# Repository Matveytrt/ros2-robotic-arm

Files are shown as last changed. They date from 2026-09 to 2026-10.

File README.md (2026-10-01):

# ROS2 Robotic Arm

Роборука-манипулятор с 6 степенями свободы из оргстекла. Управление на ROS2 + micro-ROS (ESP32), цифровой двойник, обучение движениям и сортировке кубиков.

Авторы: Разгулов Матвей, Клеукин Вячеслав (Б01-501).

## Структура
| Папка | Что там |
|---|---|
| `roboruka_v1/` | механика: параметрические детали (CadQuery), STEP, DXF для лазера, PDF-чертежи, сборка. Подробности в [roboruka_v1/README.md](roboruka_v1/README.md) |
| `RULES.md` | правила совместной работы: модули, статусы деталей, цикл правки |
| _дальше_ | прошивка micro-ROS, ROS2-пакеты, URDF и цифровой двойник |

## Кинематика v1
J1 основание: NEMA17, прямой привод, упорный подшипник 51106 · J2 плечо: MG996R · J3 локоть: MG996R · J4 наклон кисти: MG90S · J5 вращение клешни: MG90S · J6 захват: MG90S.
Плечо и предплечье по 100 мм. Оргстекло 5 мм на силовые детали, 3 мм на кисть и клешню.

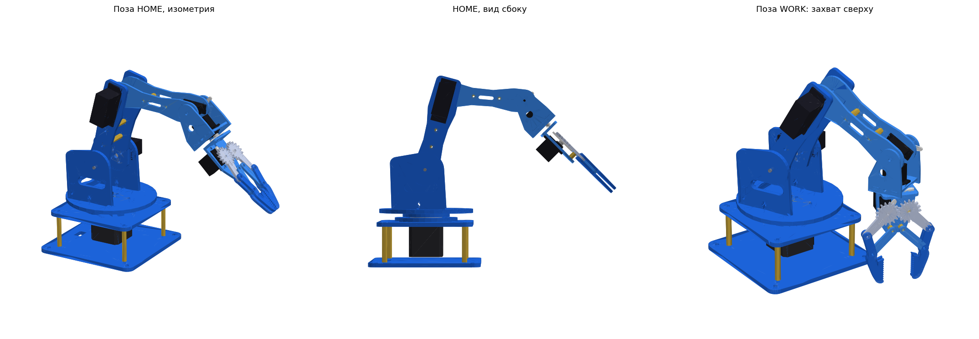
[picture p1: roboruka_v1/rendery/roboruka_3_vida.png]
сборка


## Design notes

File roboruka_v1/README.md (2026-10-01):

# Роборука 6 DOF из оргстекла: заготовки для SolidWorks

## Что внутри
| Папка | Что там |
|---|---|
| `step_detali/` | 21 деталь, каждая в своём STEP. Деталь лежит плоско: контур в плоскости XY, толщина идёт по +Z |
| `sborka/` | сборка в STEP в двух позах: `HOME` и `WORK` (захват сверху). Серво, подшипник, стойки M3 и NEMA17 в ней упрощённые. В сборке «вверх» — это +Y, как принято в SolidWorks |
| `dxf_laser/` | контуры деталей для лазера. `00_list_3mm.dxf` и `00_list_5mm.dxf` — готовые раскладки листов |
| `chertezhi/` | PDF-чертежи: лист 0 — общая схема, дальше по листу на деталь с координатами всех отверстий |
| `rendery/` | картинки сборки и вариантов стиля |
| `scripts/` | исходники. Все размеры лежат в `params.py` |

## Кинематика
- **J1 основание**: NEMA17, прямой привод через фланцевую муфту Ø5, поворот ±180°. Стол лежит на упорном подшипнике 51106, центрируют его кольца 03 и 05.
- **J2 плечо**: MG996R на левой стойке (06), качалка крепится к плечу 09. Правое плечо 10 качается на оси M4 в стойке 07.
- **J3 локоть**: MG996R стоит прямо в локте, на правом плече 10. Его качалка несёт правое предплечье 12, тяги нет.
- **J4 наклон кисти**: MG90S в левом предплечье 11, качалка крепится к кисти 13.
- **J5 вращение клешни**: MG90S на плите 15. Качалка несёт заднюю плиту клешни 16, ось вращения совпадает с осью кисти.
- **J6 захват**: MG90S, пара шестерён m1.5 z16 и два параллелограмма. Пальцы-«клыки» двигаются параллельно, раскрытие 0.6…51 мм.
- Плечо L1 = 100 мм, предплечье L2 = 100 мм, ось плеча на высоте 121 мм от стола.

## Толщины
- 5 мм: 01–10 (основание, стол, кольца, стойки, перемычка, плечи)
- 3 мм: 11–21 (предплечья, кисть, клешня). Палец 21 нужно вырезать 4 шт., поводок 20 — 2 шт.

## Что сверить штангенциркулем (помечено `!!! ПРОВЕРИТЬ` в params.py)
1. **MG996R**: корпус 40.7×19.7, межцентровое ушек 49.5×10, высота от ушка до качалки (`SV_HORN_FACE`), окружность отверстий алюминиевой качалки `HORN_PCD = 18`.
2. **MG90S**: те же размеры, что в клешне v2.
3. **Вылет вала NEMA17** и окружность отверстий фланцевой муфты `CPL_PCD`.

## Крепёж (основной)
- Основание: 4 стойки M3×45 мама-мама, 8 винтов M3×8. NEMA17 крепится 4 винтами M3×10 к плите 02.
- Кольцо 03 крепится к плите 02 винтами M3×12 с гайкой. Кольцо 05 крепится к столу 04 винтами M3×10 в резьбу, нарезанную метчиком.
- Стойки вставляются в стол шипами в пазы и притягиваются Т-соединением (винт M3×12 + гайка в Т-пазу). Так же крепится перемычка 08.
- Плечо: 2 стойки M3×41.5 (или шпилька M3 + трубка), ось M4×50 с нейлоновой гайкой в стойке 07.
- Предплечье: 2 стойки M3×25. Кисть: плита 15 собирается на Т-пазы.
- Клешня: 3 стойки M3×8, шарниры пальцев M3×16 с нейлоновой гайкой.

## Как менять
1. Поменяй число в `scripts/params.py` (например, `L1`, `STYLE`, `FINGER_STYLE`).
2. `pip install cadquery ezdxf shapely matplotlib`
3. `python export.py ../out` пересоберёт STEP, DXF, PDF и сборку. `python check.py` проверит столкновения в 11 позах.

## Импорт в SolidWorks
Открой `.step` через «Файл → Открыть». Деталь придёт телом без дерева. Чтобы получить редактируемый эскиз, открой DXF той же детали: он встанет эскизом на плоскость, дальше «Вытянутая бобышка» на 3 или 5 мм.

## Работа в SolidWorks (папка `solidworks/`)
| Что | Где |
|---|---|
| нативные детали с деревом построения | `solidworks/parts/NN_imya.SLDPRT` |
| общие размеры (T3, T5, D_M3, D_M2, L1, L2…) | `solidworks/params.txt` (детали связаны с ним) |
| описание эскизов для макроса | `solidworks/data/*.txt` (генерирует `scripts/sw_export.py`) |
| макросы | `solidworks/macros/BuildParts.swp`, `ExportAll.swp` (исходники в `.bas`) |

**Дерево каждой детали:**
- `Eskiz_kontur` → `Plastina`: контур, окна, пазы; бобышка на толщину `T3`/`T5`
- `Eskiz_otverstiya` → `Otverstiya`: круглые отверстия с размерами, вырез насквозь. Отверстия M3 привязаны к `D_M3`.

**Как править деталь:**
1. Открой `solidworks/parts/NN_….SLDPRT`.
2. Двойной клик по `Eskiz_otverstiya` или `Eskiz_kontur` → правка → выйти из эскиза → Ctrl+B.
3. Ctrl+S → макрос ExportAll → `python scripts/pipeline.py` → коммит.
4. В `parts.csv` поставь детали статус `manual`, чтобы её больше не перезаписывал генератор.

**Общий размер для всех деталей** (например, зазор под M3): поменяй `"D_M3" = 3.4` в `params.txt` → открой деталь → Ctrl+Q.

**Макросы:** Инструменты → Макрос → Выполнить → `solidworks/macros/…swp`.
- `BuildParts`: спросит номера деталей (`09,20`), пусто = все `gen`.
- `ExportAll`: STEP открытой детали или всех деталей в `step_detali/`.

## Модули (подсборки)
- Таблица интерфейсов `PORTS` в `scripts/moduli.py`: модуль → родитель, шарнир, точка порта и ось. По ней же потом соберём URDF для ROS2.
- `python scripts/moduli.py ..` раскладывает компоненты по модулям в их собственных СК и проверяет, что модули, собранные по портам в другой позе, совпадают с исходной сборкой (сейчас расхождение 1e-12 мм). Результат: `sborka/moduli/M*.step` и данные для SolidWorks в `solidworks/moduli/*.txt`.
- Макрос **BuildAssembly** (`solidworks/macros/BuildAssembly.swp`):
  - покупные изделия `solidworks/pokupnye/*.step` переводит в SLDPRT;
  - собирает `solidworks/moduli/M1…M6.SLDASM` (детали внутри модуля зафиксированы);
  - собирает `solidworks/roboruka_HOME.SLDASM` из шести модулей в позе HOME.
- Пока модули в общей сборке тоже зафиксированы. Подвижные сопряжения по портам (крутить руку мышкой) — следующий шаг.

Правила совместной работы — в [`../RULES.md`](../RULES.md).

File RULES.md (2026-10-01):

# Правила работы над роборукой (Матвей + Claude)

## 1. Модули и интерфейсы
Рука собирается из шести модулей, как из лего. У каждого модуля своя система координат: **начало на входном шарнире**.

| Модуль | Детали | Вход (шарнир, ось в СК родителя) |
|---|---|---|
| M1_osnovanie | 01–03, NEMA17, подшипник 51106 | — (стоит на столе) |
| M2_platforma | 04–08, MG996R плеча, ось M4 | J1: (0, 0, 66), ось Z |
| M3_plecho | 09, 10, MG996R локтя, качалка плеча | J2: (0, 0, 55), ось −Y |
| M4_predplechye | 11, 12, MG90S наклона, качалка локтя | J3: (L1, 0, 0), ось −Y |
| M5_kist | 13–15, MG90S вращения, качалка наклона | J4: (L2, 0, 0), ось −Y |
| M6_kleshnya | 16–21, MG90S захвата, качалка вращения | J5: (46, 0, 0), ось X |

**Интерфейс — это ровно одна строка таблицы `PORTS` в `roboruka_v1/scripts/moduli.py`**, то есть точка и ось шарнира в СК родителя. Больше нигде порты не записаны.
- Внутри модуля меняй что угодно, пока деталь не лезет на место порта.
- Качалка серво относится к модулю, который она двигает (модулю-ребёнку), а корпус серво — к модулю-родителю.
- Меняешь порт — это изменение двух модулей сразу. Пиши в коммите `M3↔M4: …`; `moduli.py` проверит, что модули по-прежнему стыкуются.
- Где лежат модули: в STEP — `sborka/moduli/M*.step`, в SolidWorks — `solidworks/moduli/M*.SLDASM`. Общая сборка из модулей: `solidworks/roboruka_HOME.SLDASM`.

## 2. У каждой детали один хозяин
Колонка `status` в `roboruka_v1/parts.csv`:
- `gen` — геометрию строит Python, а SLDPRT собирает макрос BuildParts. Деталь правим через `params.py` / `params.txt`.
- `manual` — деталь правишь ты в SolidWorks. Python её **никогда** не перегенерирует, а берёт её STEP, который сохранил SolidWorks.

Чтобы забрать деталь себе: поставь в `parts.csv` статус `manual` и закоммить. Обратно `gen` — только по договорённости, иначе потеряются ручные правки.

## 3. Геометрия детали
- **Начало координат детали = ось её главного шарнира. Не двигать.** По этой точке деталь ставится в сборку.
- Деталь лежит в плоскости «Спереди» (XY), толщина идёт в +Z.
- Толщина детали задаётся только через глобальные переменные `T3` / `T5`, отверстия M3 — через `D_M3`.
- Единицы: мм. Зазоры: M3 → 3.3 мм, паз-шип 0.2 мм.

## 4. Файлы и имена
- `NN_imya.SLDPRT` и `NN_imya.step` с одинаковым именем. Номер детали не меняется никогда.
- Никаких `_v2`, `_final`, `_new`: версии хранит git.
- Все SLDPRT/SLDASM лежат внутри `Fabrica`, иначе сломаются ссылки сборок.

## 5. Цикл после правки
1. Поправил деталь в SolidWorks → сохранил (Ctrl+S).
2. Макрос **ExportAll** → STEP в `step_detali/`.
3. `python scripts/pipeline.py` → DXF, листы на резку, чертежи, модули, проверка портов и столкновений. Можно попросить Claude.
4. Если менялся состав или положение деталей в модуле → макрос **BuildAssembly** (пересоберёт `M*.SLDASM` и `roboruka_HOME.SLDASM`).
5. `git add -A && git commit -m "M6: палец длиннее на 5 мм"` → `git push`.
- Один коммит = одна осмысленная правка.
- Эксперименты делаем в ветке: `git switch -c opyt-palec`.

## 6. Замеры
Всё, что измерено штангенциркулем, вносим в `params.py` с пометкой `# измерено ДД.ММ`. Пока стоит `!!! ПРОВЕРИТЬ`, размер считается предварительным.

## 7. Claude обещает
- Сначала задаёт вопросы, потом проектирует. Никакой отсебятины.
- Не трогает детали `manual` и не меняет интерфейсы молча.
- Не пушит без Матвея. Сам коммитит только то, что сделал, с понятным сообщением.
- После каждой правки объясняет, что поменял и почему.

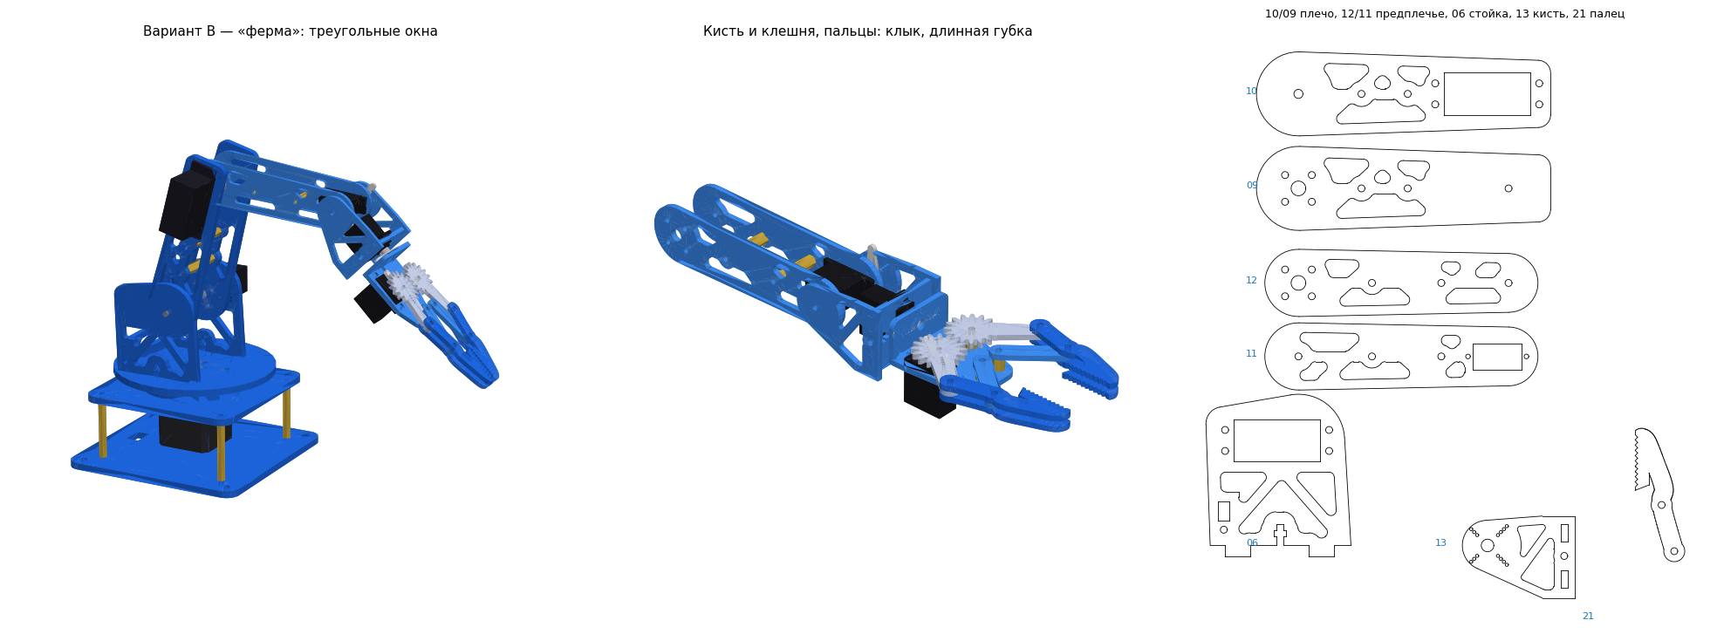
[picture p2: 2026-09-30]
roboruka_v1/rendery/variant_B.png

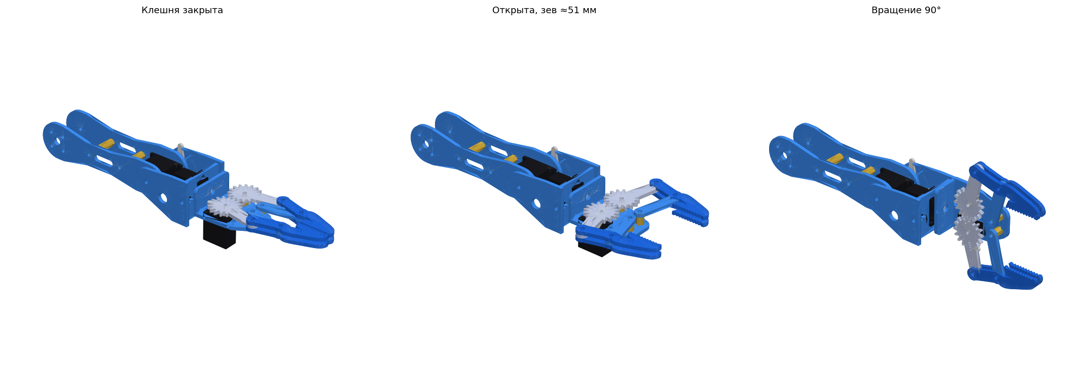
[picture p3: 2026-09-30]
roboruka_v1/rendery/kist_i_kleshnya.png

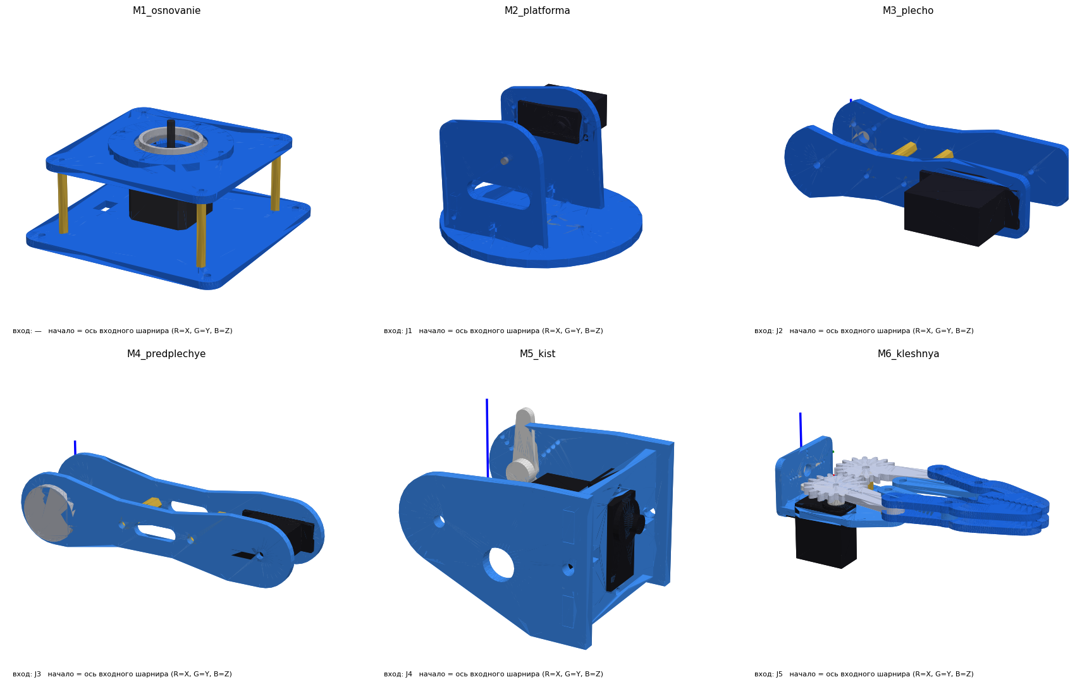
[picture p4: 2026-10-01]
roboruka_v1/rendery/moduli.png

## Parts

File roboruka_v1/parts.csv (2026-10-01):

pid | name | module | status | thickness | qty | note
01 | 01_osnovanie_niz | M1_osnovanie | gen | 5 | 1 | Основание нижнее
02 | 02_plita_dvigatelya | M1_osnovanie | gen | 5 | 1 | Плита двигателя (верх основания)
03 | 03_kolco_nizhnee | M1_osnovanie | gen | 5 | 1 | Кольцо-центратор нижнее (51106)
04 | 04_povorotny_stol | M2_platforma | gen | 5 | 1 | Поворотный стол
05 | 05_kolco_verhnee | M2_platforma | gen | 5 | 1 | Кольцо-центратор верхнее (резьба M3 метчиком)
06 | 06_stoyka_levaya | M2_platforma | gen | 5 | 1 | Стойка левая (MG996R плеча)
07 | 07_stoyka_pravaya | M2_platforma | gen | 5 | 1 | Стойка правая (ось M4)
08 | 08_peremychka | M2_platforma | gen | 5 | 1 | Задняя перемычка стоек
09 | 09_plecho_levoe | M3_plecho | gen | 5 | 1 | Плечо левое (на качалке MG996R плеча)
10 | 10_plecho_pravoe | M3_plecho | gen | 5 | 1 | Плечо правое (MG996R локтя)
11 | 11_predplechye_levoe | M4_predplechye | gen | 3 | 1 | Предплечье левое (MG90S наклона)
12 | 12_predplechye_pravoe | M4_predplechye | gen | 3 | 1 | Предплечье правое (на качалке локтя)
13 | 13_kist_A | M5_kist | gen | 3 | 1 | Кисть A (на качалке наклона)
14 | 14_kist_B | M5_kist | gen | 3 | 1 | Кисть B (на оси)
15 | 15_kist_plita | M5_kist | gen | 3 | 1 | Плита сервы вращения
16 | 16_kleshnya_zad | M6_kleshnya | gen | 3 | 1 | Задняя плита клешни (на качалке вращения)
17 | 17_ladon | M6_kleshnya | gen | 3 | 1 | Ладонь клешни
18 | 18_shesternya_R | M6_kleshnya | gen | 3 | 1 | Шестерня-рычаг R ведущая (на качалке)
19 | 19_shesternya_L | M6_kleshnya | gen | 3 | 1 | Шестерня-рычаг L ведомая
20 | 20_povodok | M6_kleshnya | gen | 3 | 2 | Поводок (левый = правый)
21 | 21_palec | M6_kleshnya | gen | 3 | 4 | Палец (4 одинаковых, левые перевёрнуты)

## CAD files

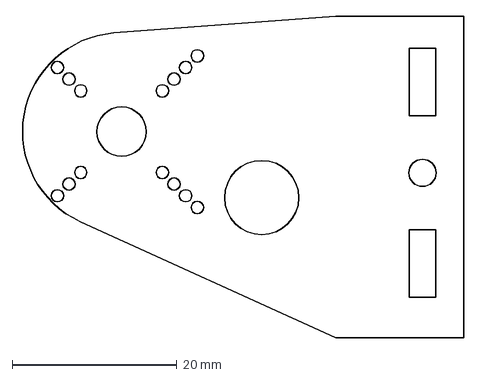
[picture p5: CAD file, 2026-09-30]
roboruka_v1/dxf_laser/13_kist_A.dxf
54.3 x 39.0 mm

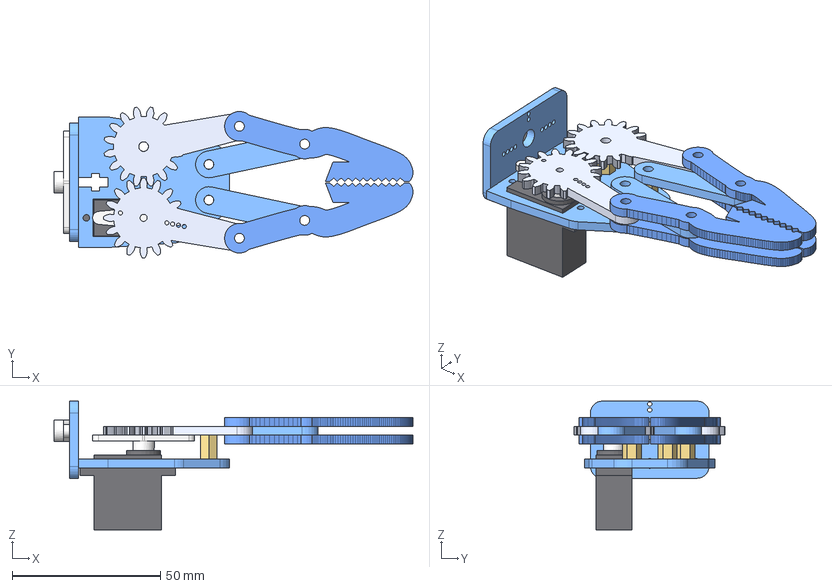
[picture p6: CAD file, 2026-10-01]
roboruka_v1/sborka/moduli/M6_kleshnya.step
121.0 x 50.8 x 43.4 mm
16_kleshnya_zad
17_ladon
18_shesternya_R
19_shesternya_L
20_povodok_R
20_povodok_L
21_palec_R_verh
21_palec_R_niz
21_palec_L_verh
21_palec_L_niz
MG90S_zahvat
kachalka_zahvat
stoyka_M3x8_kleshnya_0
stoyka_M3x8_kleshnya_1
stoyka_M3x8_kleshnya_2
kachalka_vrashenie

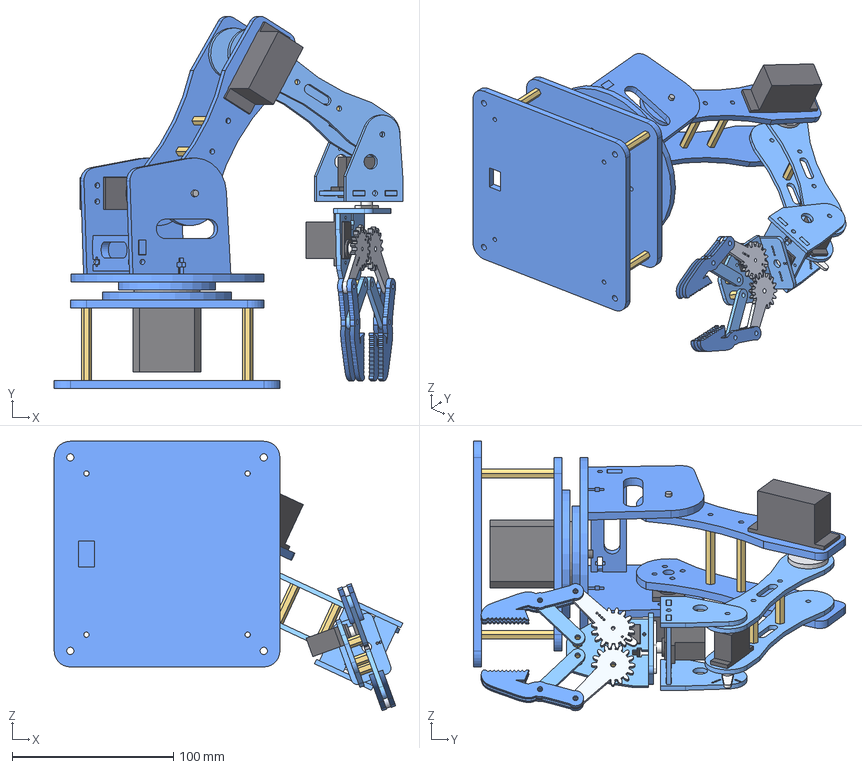
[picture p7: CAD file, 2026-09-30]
roboruka_v1/sborka/roboruka_sborka_WORK.step
216.2 x 230.7 x 167.2 mm
01_osnovanie_niz
02_plita_dvigatelya
03_kolco_nizhnee
stoyka_M3x45
stoyka_M3x45_2
stoyka_M3x45_3
stoyka_M3x45_4
NEMA17
51106_nizhnyaya_shayba
51106_separator
51106_verhnyaya_shayba
05_kolco_verhnee
04_povorotny_stol
mufta_flanc_5mm
06_stoyka_levaya
07_stoyka_pravaya
08_peremychka
MG996R_plecho
kachalka_plecho
MG996R_lokot
kachalka_lokot
os_M4_plecho
09_plecho_levoe
10_plecho_pravoe
11_predplechye_levoe
12_predplechye_pravoe
stoyka_M3x41.5_plecho_0
stoyka_M3x41.5_plecho_1
stoyka_M3x25_predpl_0
stoyka_M3x25_predpl_1
MG90S_naklon
13_kist_A
14_kist_B
15_kist_plita
kachalka_naklon
MG90S_vrashenie
16_kleshnya_zad
17_ladon
18_shesternya_R
19_shesternya_L
20_povodok_R
20_povodok_L
21_palec_R_verh
21_palec_R_niz
21_palec_L_verh
21_palec_L_niz
MG90S_zahvat
kachalka_zahvat
stoyka_M3x8_kleshnya_0
stoyka_M3x8_kleshnya_1
stoyka_M3x8_kleshnya_2
kachalka_vrashenie

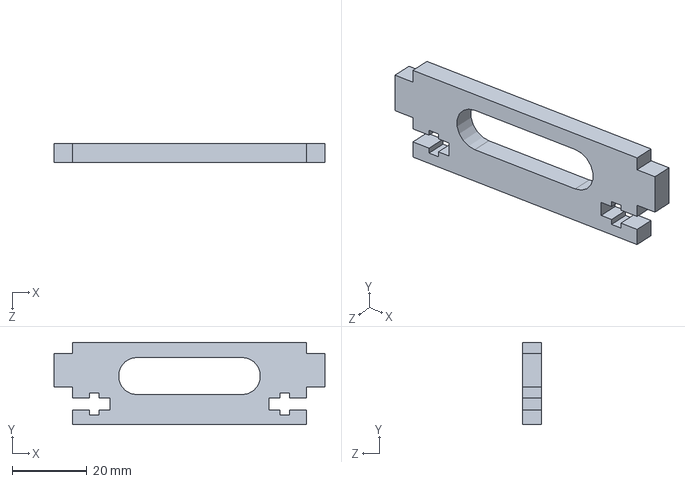
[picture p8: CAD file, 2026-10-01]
roboruka_v1/solidworks/parts/08_peremychka.SLDPRT
72.5 x 22.0 x 5.00 mm

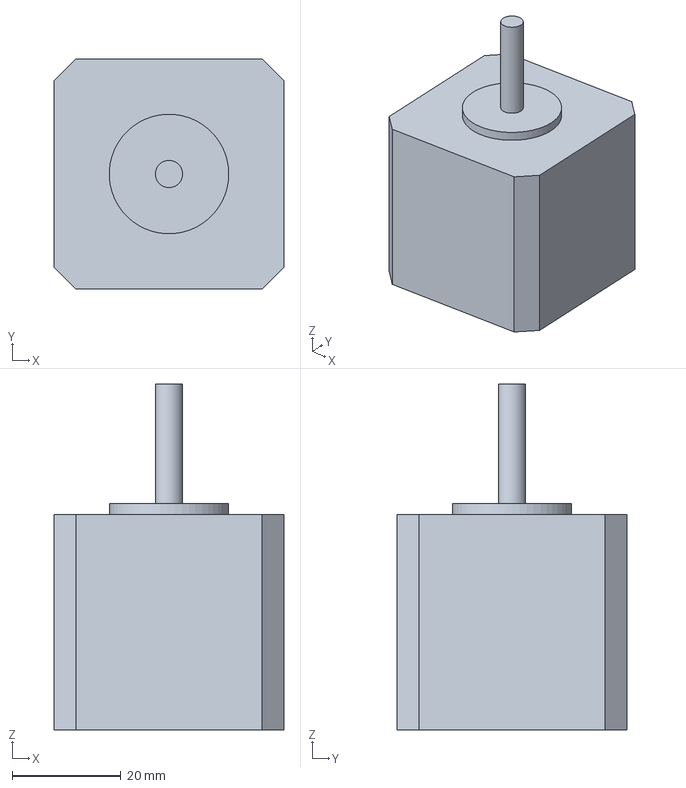
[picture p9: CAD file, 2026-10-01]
roboruka_v1/solidworks/pokupnye/NEMA17.step
42.3 x 42.3 x 63.7 mm

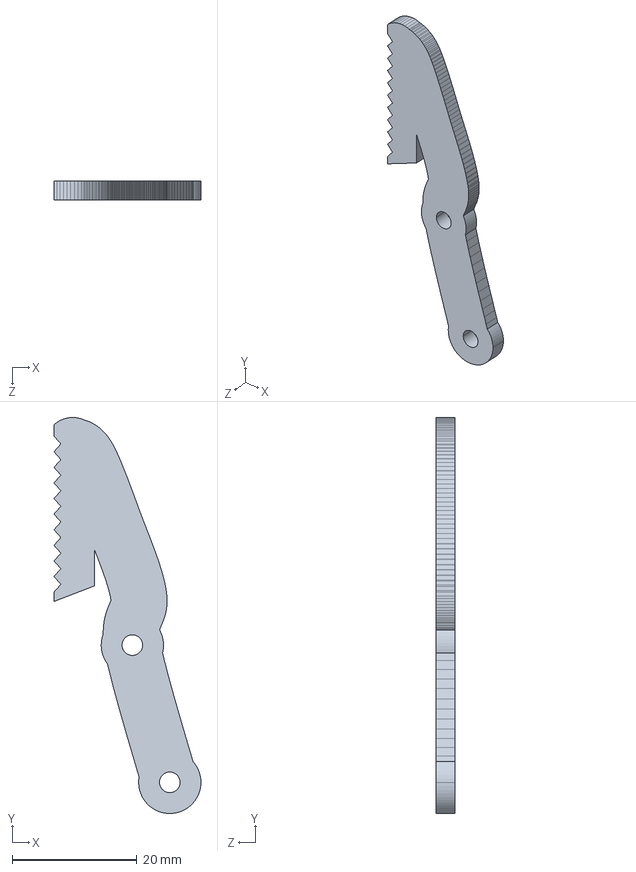
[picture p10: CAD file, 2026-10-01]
roboruka_v1/step_detali/21_palec.step
23.6 x 63.5 x 3.00 mm

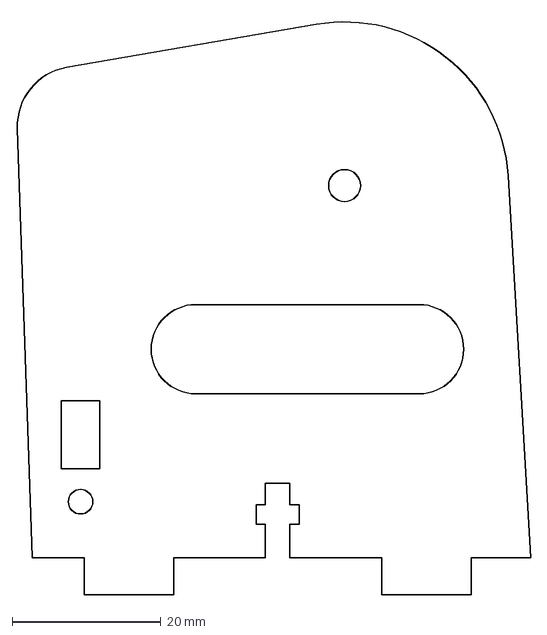
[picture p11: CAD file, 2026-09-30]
roboruka_v1/dxf_laser/07_stoyka_pravaya.dxf
69.1 x 77.8 mm

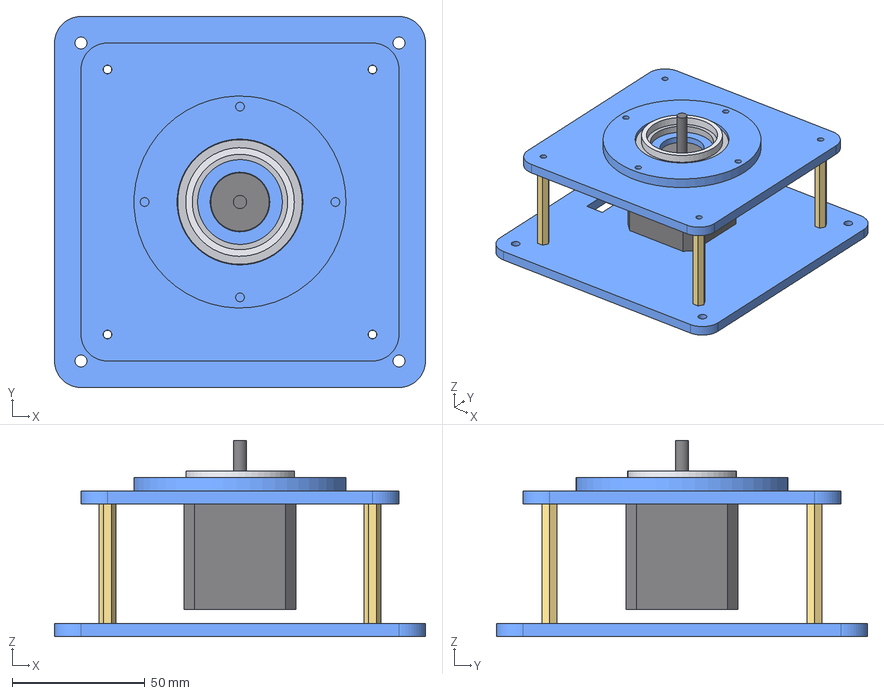
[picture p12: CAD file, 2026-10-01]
roboruka_v1/sborka/moduli/M1_osnovanie.step
140.0 x 140.0 x 74.0 mm
01_osnovanie_niz
02_plita_dvigatelya
03_kolco_nizhnee
stoyka_M3x45
stoyka_M3x45_2
stoyka_M3x45_3
stoyka_M3x45_4
NEMA17
51106_nizhnyaya_shayba
51106_separator

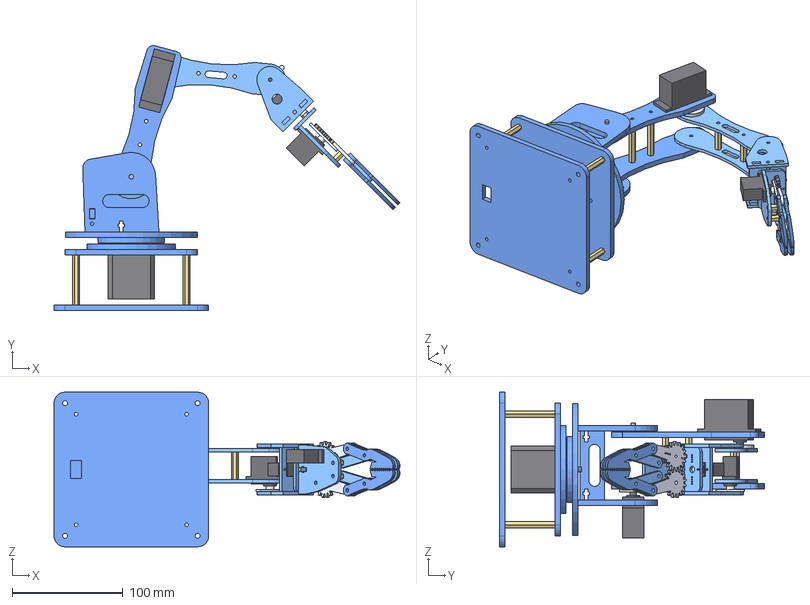
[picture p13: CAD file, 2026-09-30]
roboruka_v1/sborka/roboruka_sborka_HOME.step
313.1 x 239.7 x 140.0 mm
01_osnovanie_niz
02_plita_dvigatelya
03_kolco_nizhnee
stoyka_M3x45
stoyka_M3x45_2
stoyka_M3x45_3
stoyka_M3x45_4
NEMA17
51106_nizhnyaya_shayba
51106_separator
51106_verhnyaya_shayba
05_kolco_verhnee
04_povorotny_stol
mufta_flanc_5mm
06_stoyka_levaya
07_stoyka_pravaya
08_peremychka
MG996R_plecho
kachalka_plecho
MG996R_lokot
kachalka_lokot
os_M4_plecho
09_plecho_levoe
10_plecho_pravoe
11_predplechye_levoe
12_predplechye_pravoe
stoyka_M3x41.5_plecho_0
stoyka_M3x41.5_plecho_1
stoyka_M3x25_predpl_0
stoyka_M3x25_predpl_1
MG90S_naklon
13_kist_A
14_kist_B
15_kist_plita
kachalka_naklon
MG90S_vrashenie
16_kleshnya_zad
17_ladon
18_shesternya_R
19_shesternya_L
20_povodok_R
20_povodok_L
21_palec_R_verh
21_palec_R_niz
21_palec_L_verh
21_palec_L_niz
MG90S_zahvat
kachalka_zahvat
stoyka_M3x8_kleshnya_0
stoyka_M3x8_kleshnya_1
stoyka_M3x8_kleshnya_2
kachalka_vrashenie

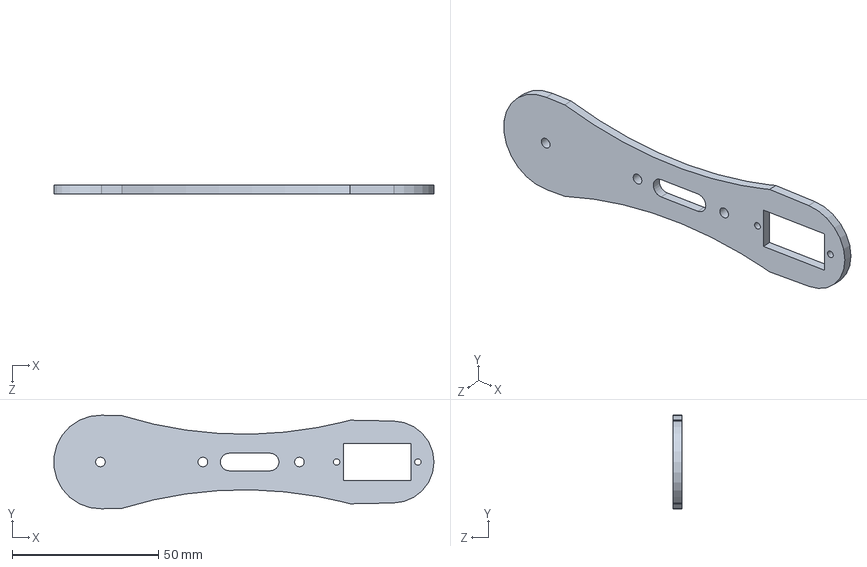
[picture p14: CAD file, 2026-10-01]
roboruka_v1/solidworks/parts/11_predplechye_levoe.SLDPRT
129.9 x 32.0 x 3.00 mm

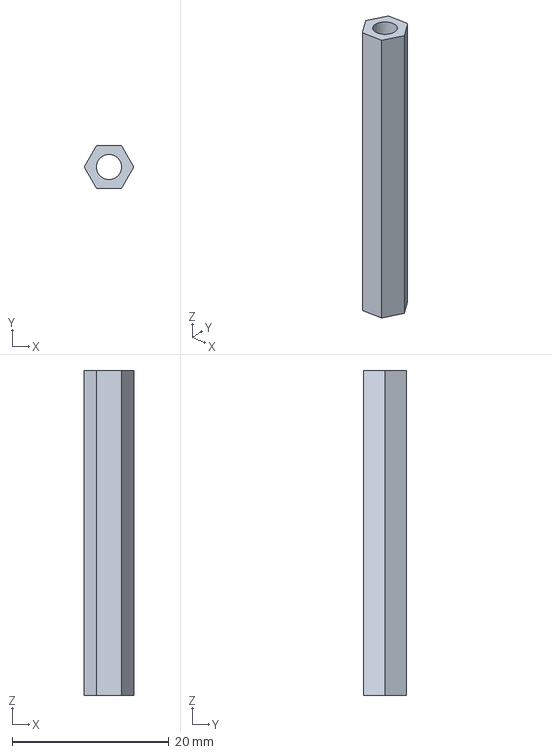
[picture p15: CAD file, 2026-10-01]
roboruka_v1/solidworks/pokupnye/stoyka_M3x41_5.step
6.35 x 5.50 x 41.5 mm

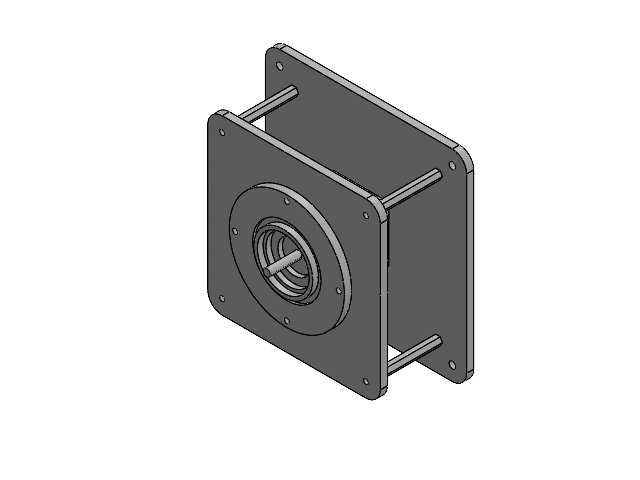
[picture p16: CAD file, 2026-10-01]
roboruka_v1/solidworks/moduli/M1_osnovanie.SLDASM
01_osnovanie_niz
02_plita_dvigatelya
03_kolco_nizhnee
stoyka_M3x45 x 4
NEMA17
51106_shayba_niz
51106_separator

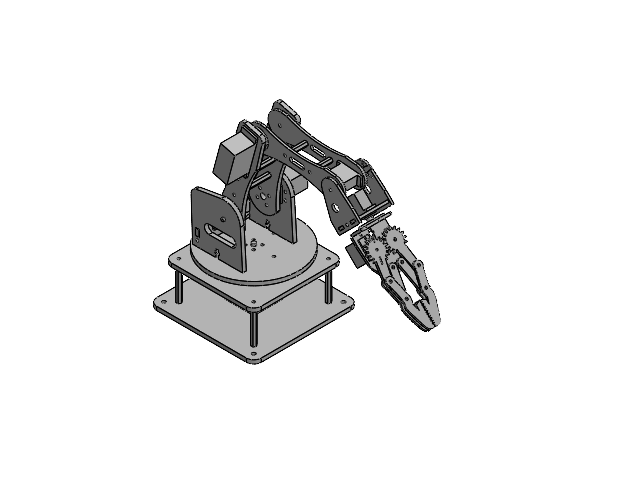
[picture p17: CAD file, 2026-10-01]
roboruka_v1/solidworks/roboruka_HOME.SLDASM
01_osnovanie_niz
02_plita_dvigatelya
03_kolco_nizhnee
stoyka_M3x45 x 4
NEMA17
51106_shayba_niz
51106_separator
51106_shayba_verh
05_kolco_verhnee
04_povorotny_stol
mufta_flanc_5mm
06_stoyka_levaya
07_stoyka_pravaya
08_peremychka
MG996R x 2
os_M4
kachalka_MG996R x 2
09_plecho_levoe
10_plecho_pravoe
stoyka_M3x41_5 x 2
11_predplechye_levoe
12_predplechye_pravoe
stoyka_M3x25 x 2
MG90S x 3
13_kist_A
14_kist_B
15_kist_plita
kachalka_MG90S x 3
16_kleshnya_zad
17_ladon
18_shesternya_R
19_shesternya_L
20_povodok x 2
21_palec x 4
stoyka_M3x8 x 3

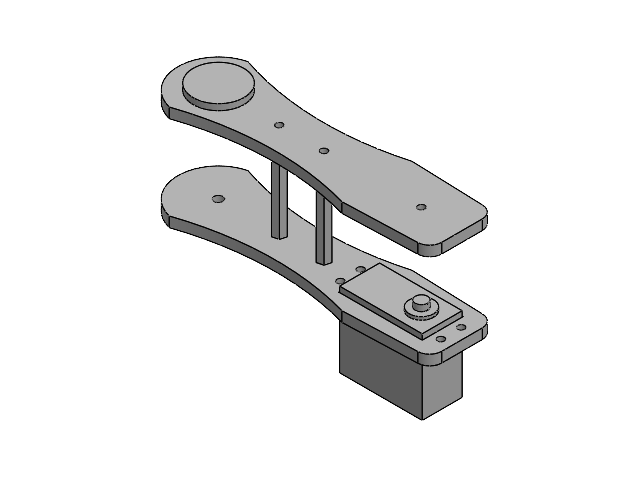
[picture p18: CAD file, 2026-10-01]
roboruka_v1/solidworks/moduli/M3_plecho.SLDASM
kachalka_MG996R
MG996R
09_plecho_levoe
10_plecho_pravoe
stoyka_M3x41_5 x 2

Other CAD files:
roboruka_v1/solidworks/moduli/M2_platforma.SLDASM
roboruka_v1/solidworks/moduli/M6_kleshnya.SLDASM
roboruka_v1/solidworks/moduli/M4_predplechye.SLDASM
roboruka_v1/solidworks/moduli/M5_kist.SLDASM
roboruka_v1/dxf_laser/00_list_3mm.dxf
roboruka_v1/dxf_laser/00_list_5mm.dxf
roboruka_v1/dxf_laser/01_osnovanie_niz.dxf
roboruka_v1/dxf_laser/02_plita_dvigatelya.dxf
roboruka_v1/dxf_laser/03_kolco_nizhnee.dxf
roboruka_v1/dxf_laser/04_povorotny_stol.dxf
roboruka_v1/dxf_laser/05_kolco_verhnee.dxf
roboruka_v1/dxf_laser/06_stoyka_levaya.dxf
roboruka_v1/dxf_laser/08_peremychka.dxf
roboruka_v1/dxf_laser/09_plecho_levoe.dxf
roboruka_v1/dxf_laser/10_plecho_pravoe.dxf
roboruka_v1/dxf_laser/11_predplechye_levoe.dxf
roboruka_v1/dxf_laser/12_predplechye_pravoe.dxf
roboruka_v1/dxf_laser/14_kist_B.dxf
roboruka_v1/dxf_laser/15_kist_plita.dxf
roboruka_v1/dxf_laser/16_kleshnya_zad.dxf
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

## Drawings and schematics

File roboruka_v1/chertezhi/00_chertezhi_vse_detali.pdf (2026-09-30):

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

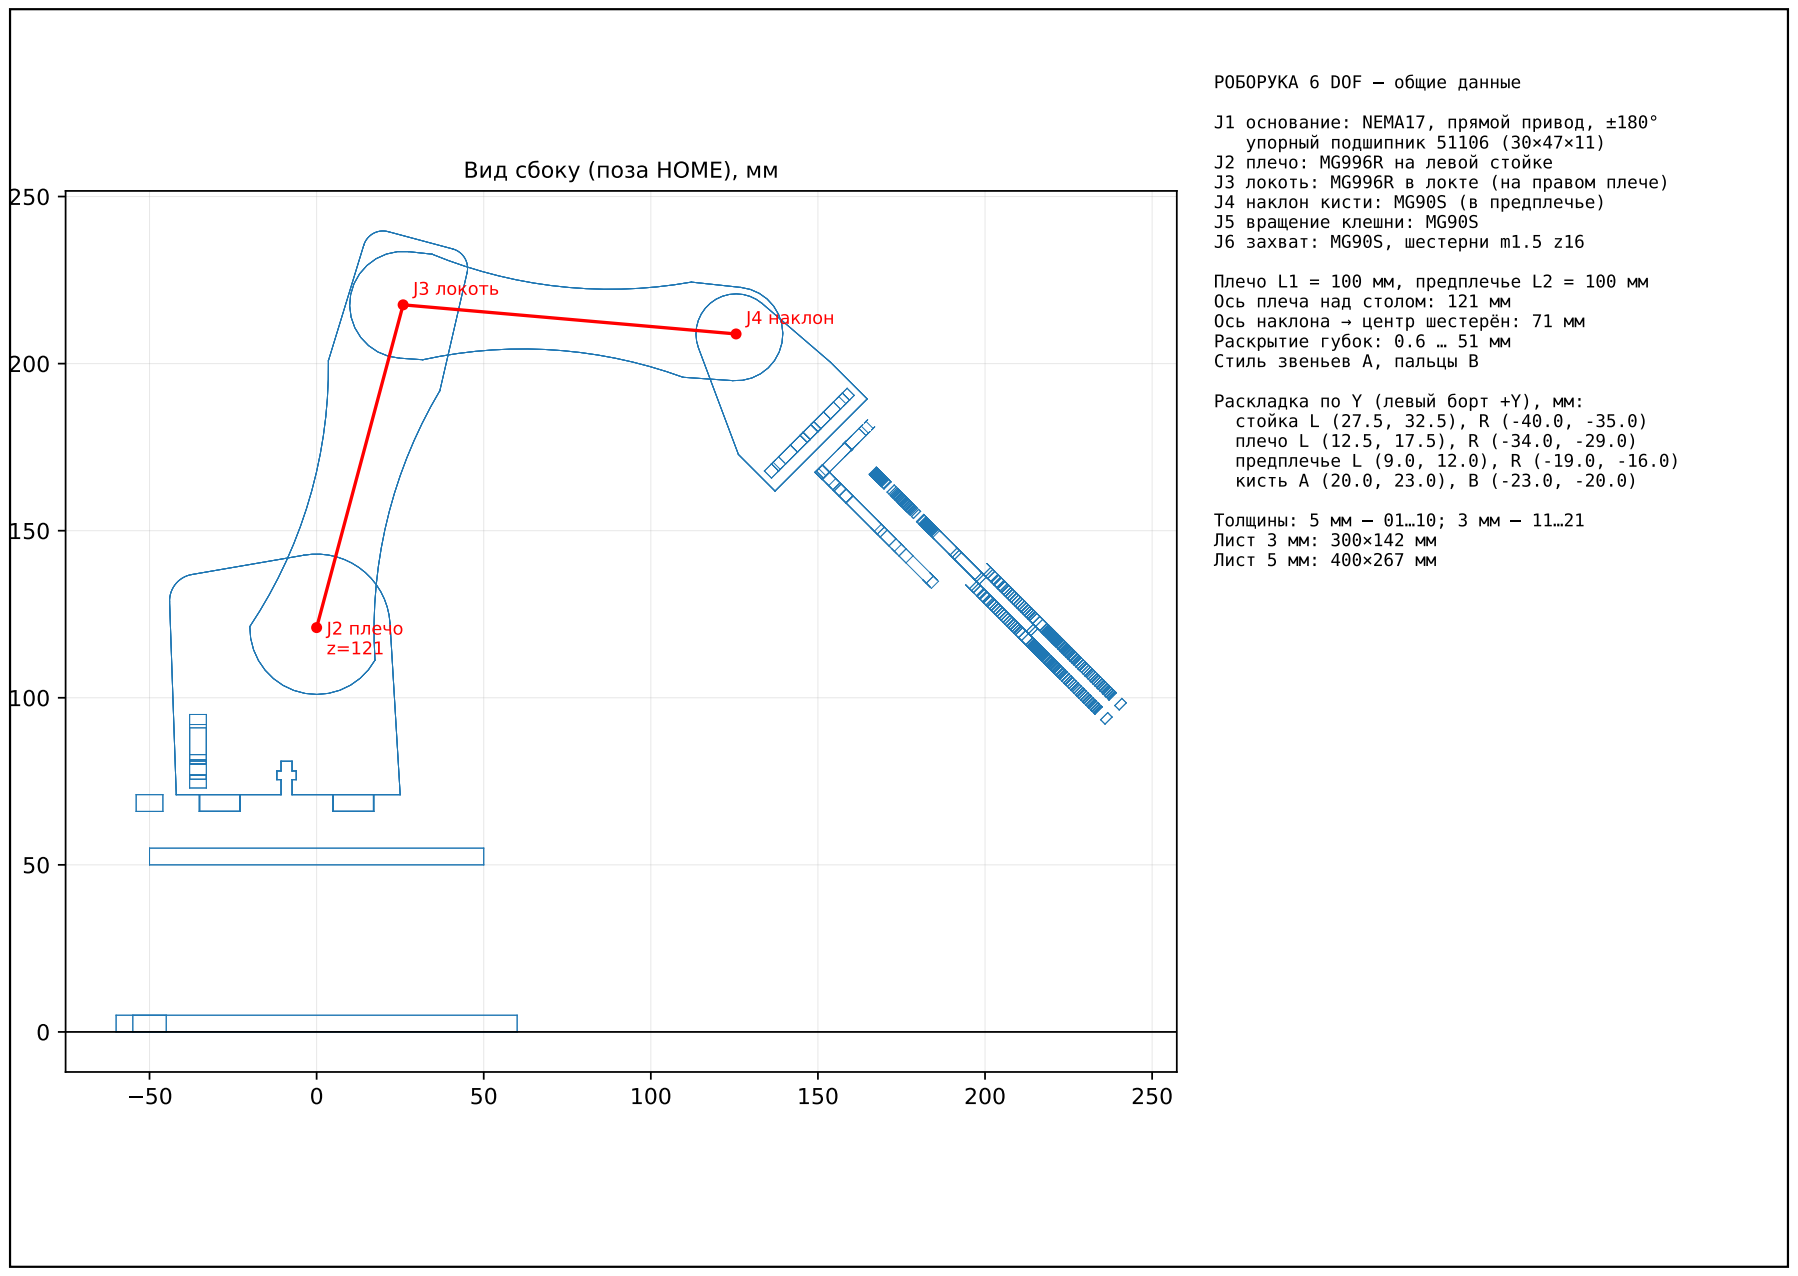
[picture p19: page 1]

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

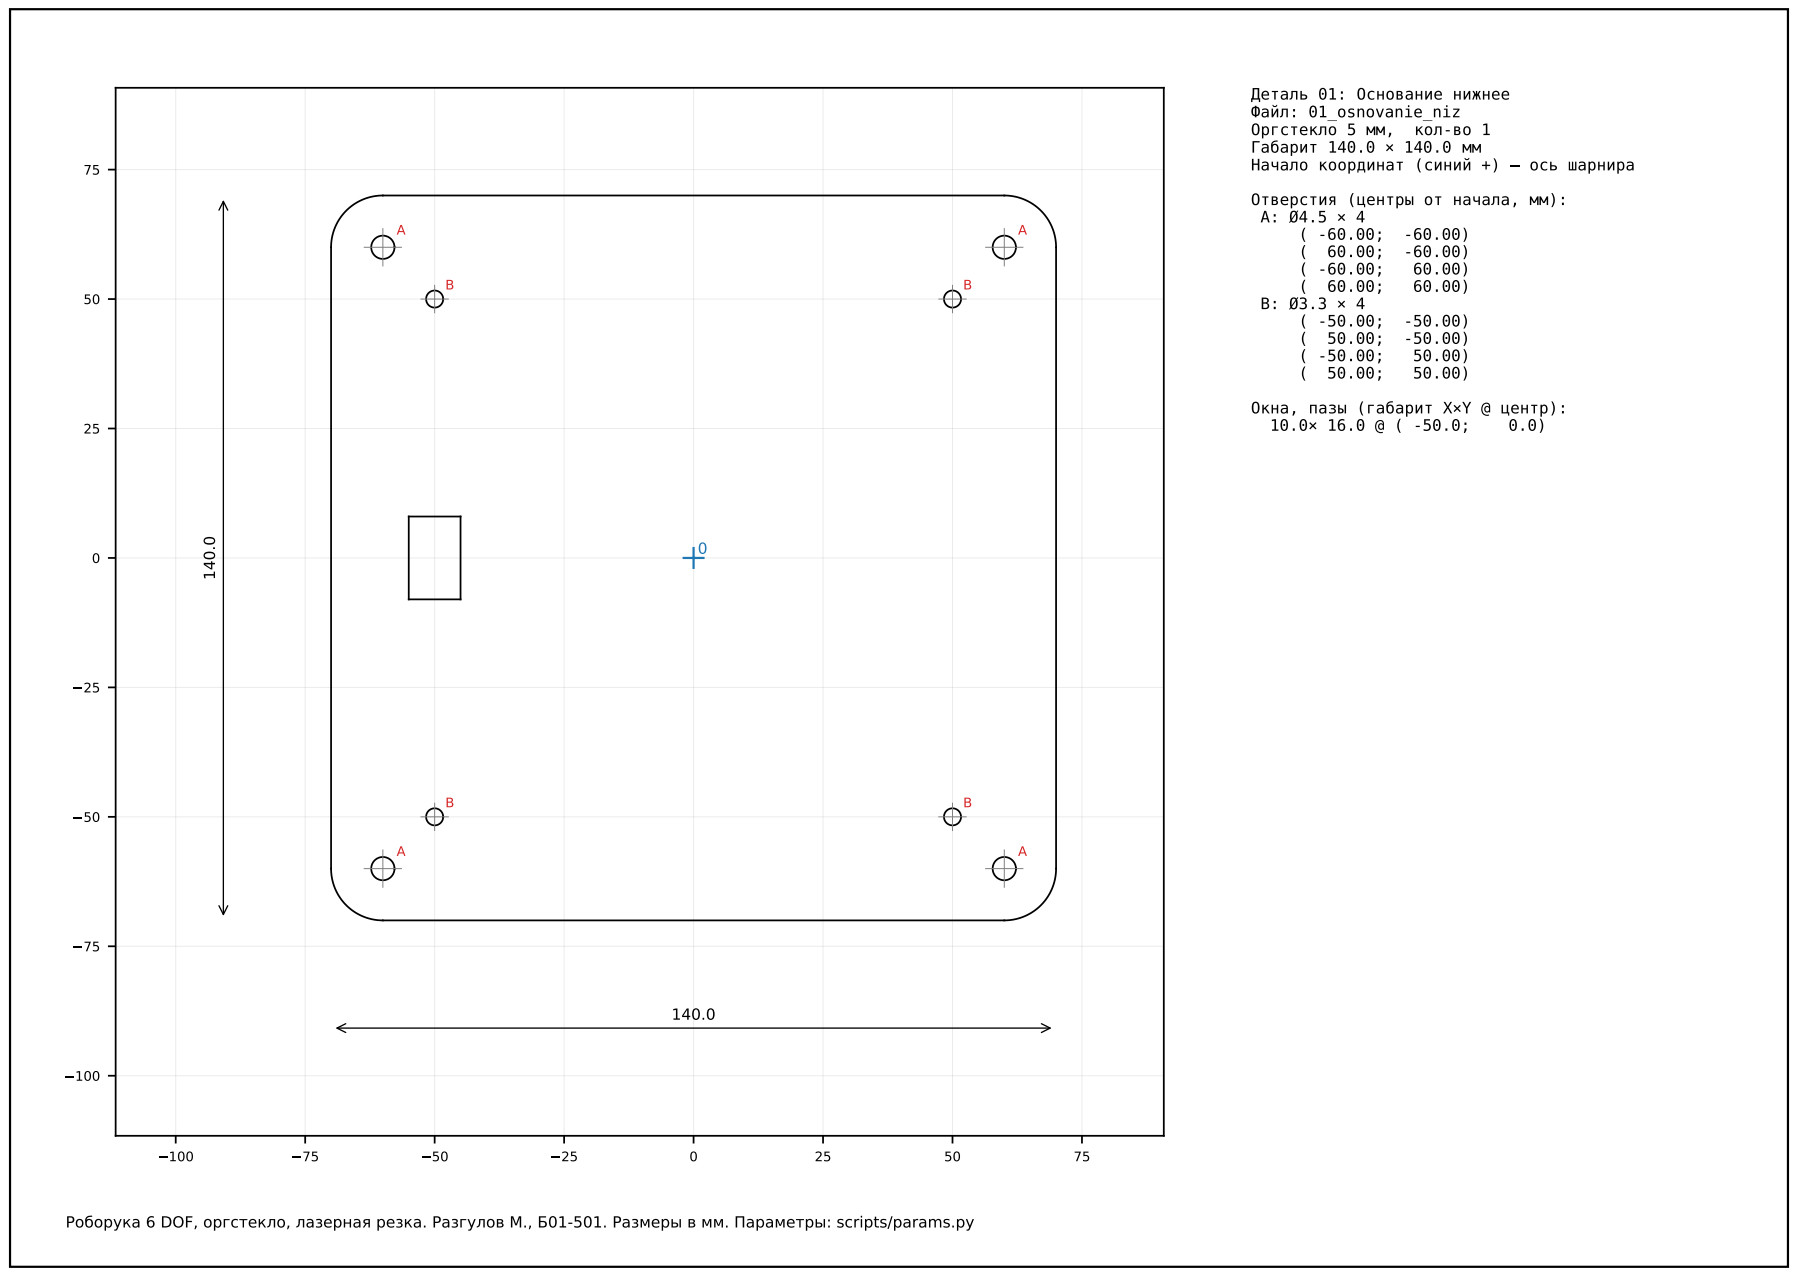
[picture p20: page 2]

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

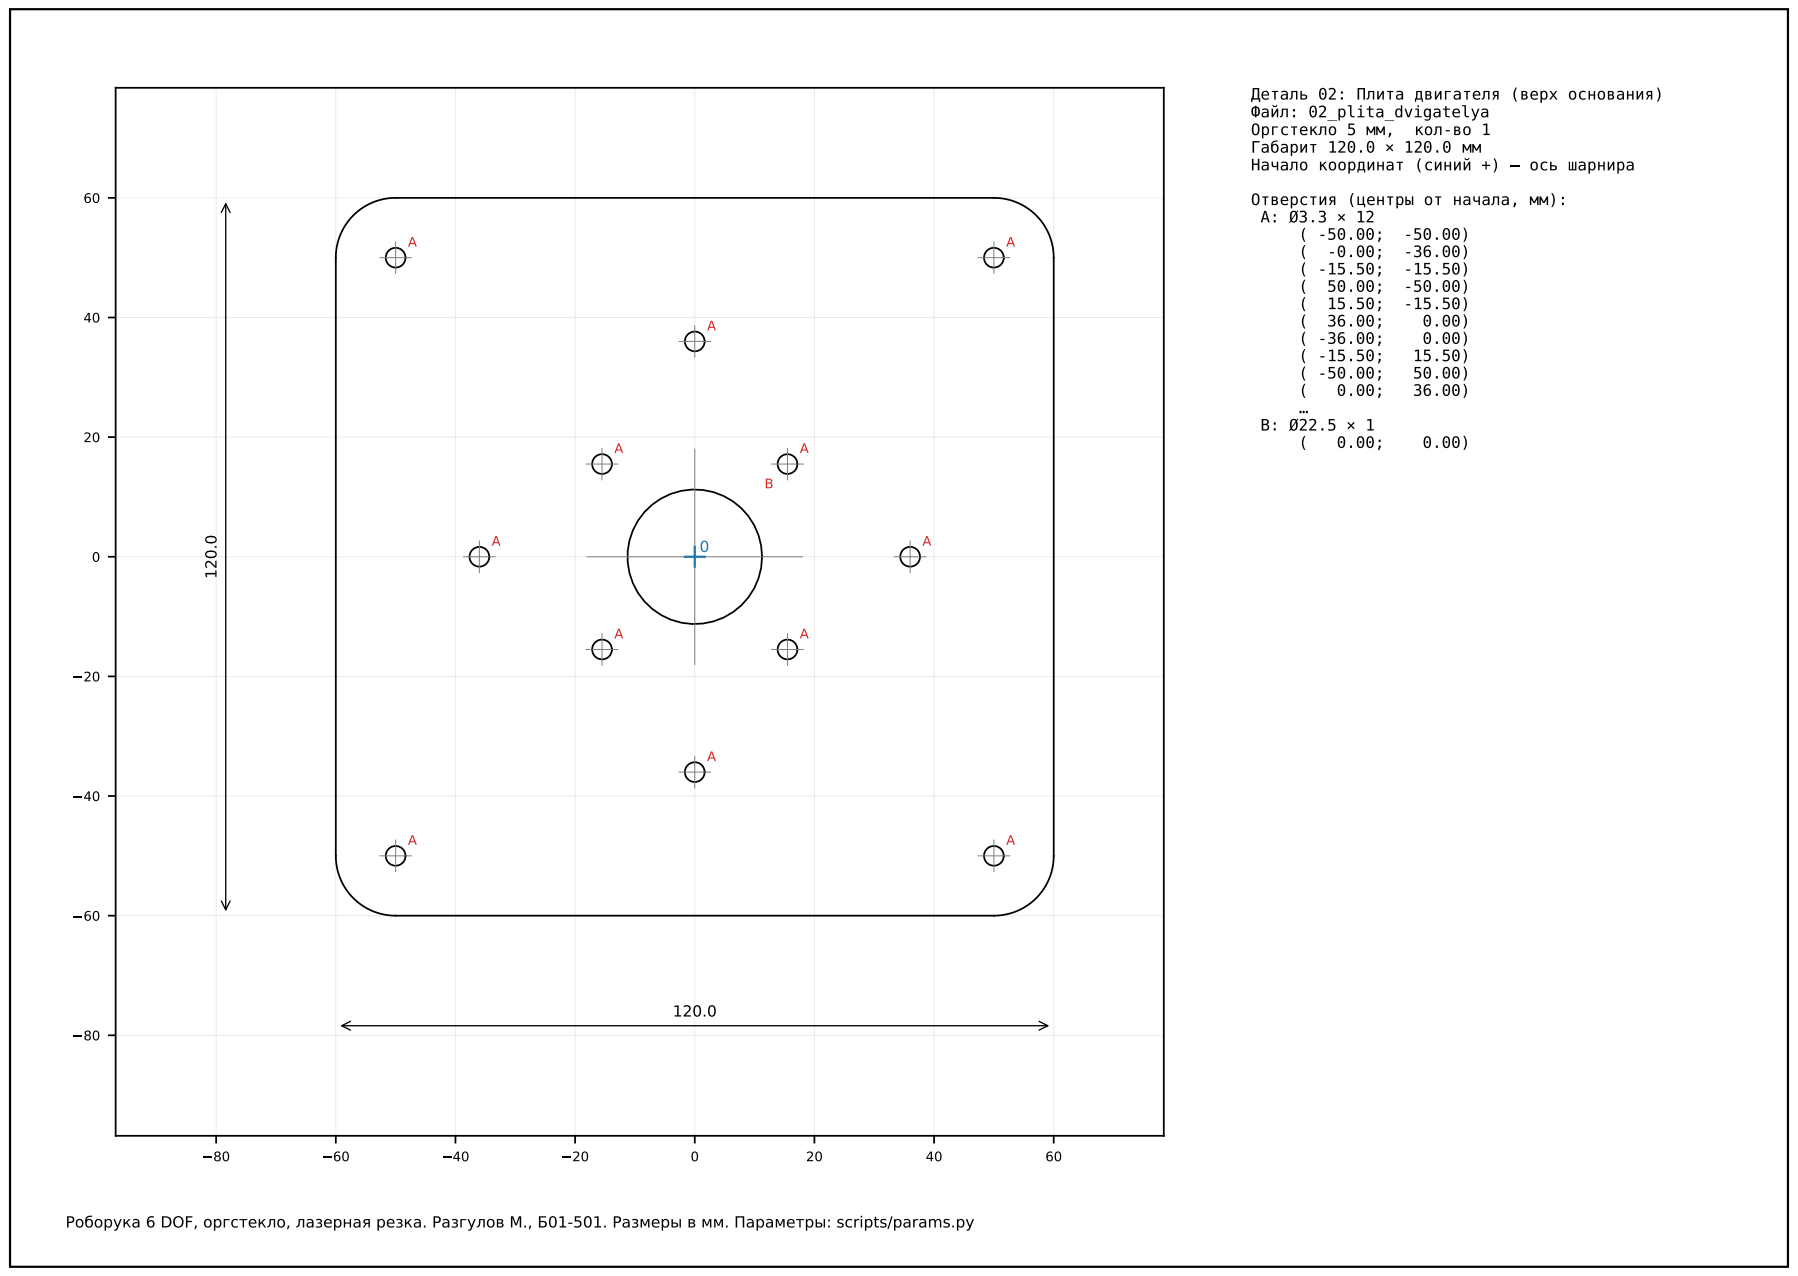
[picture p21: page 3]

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

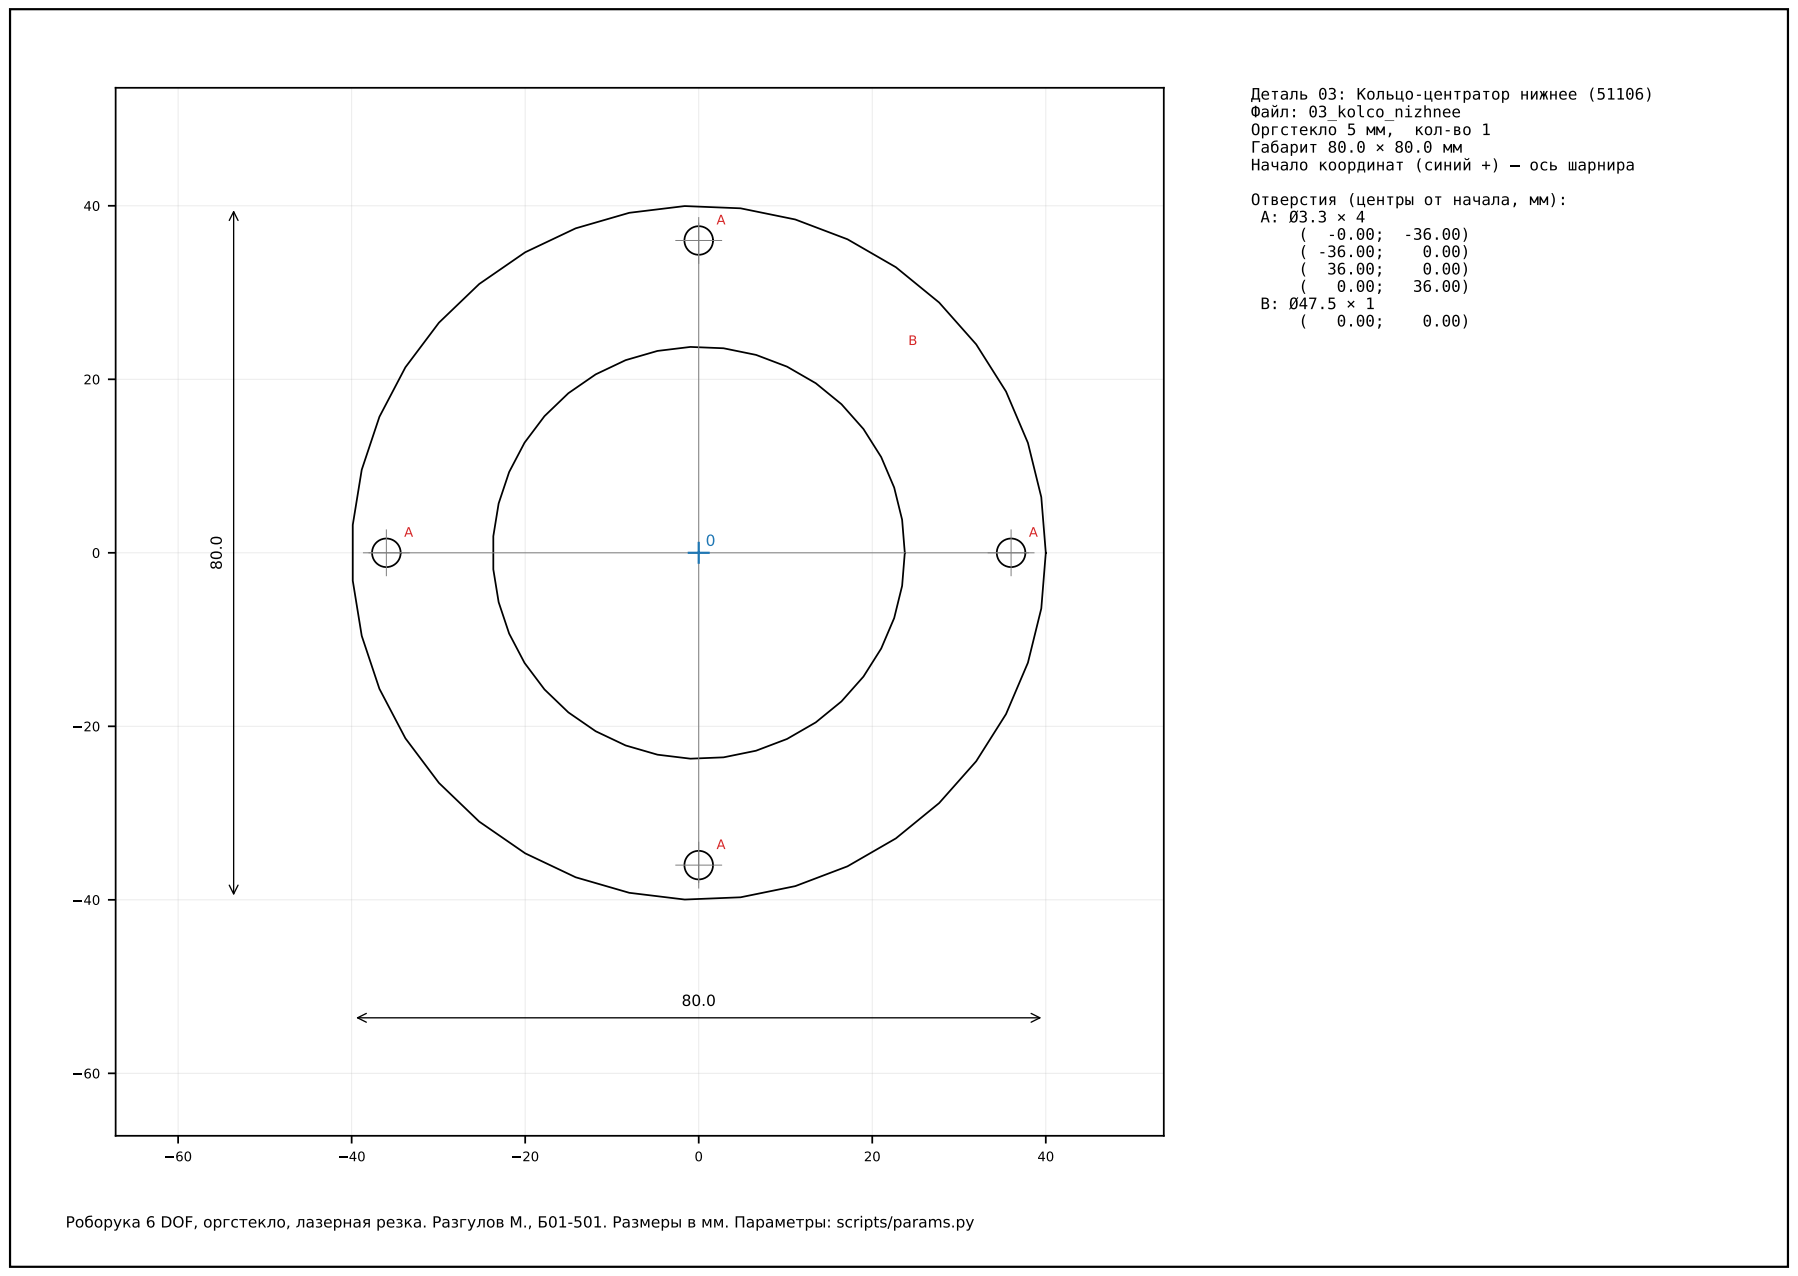
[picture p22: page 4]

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

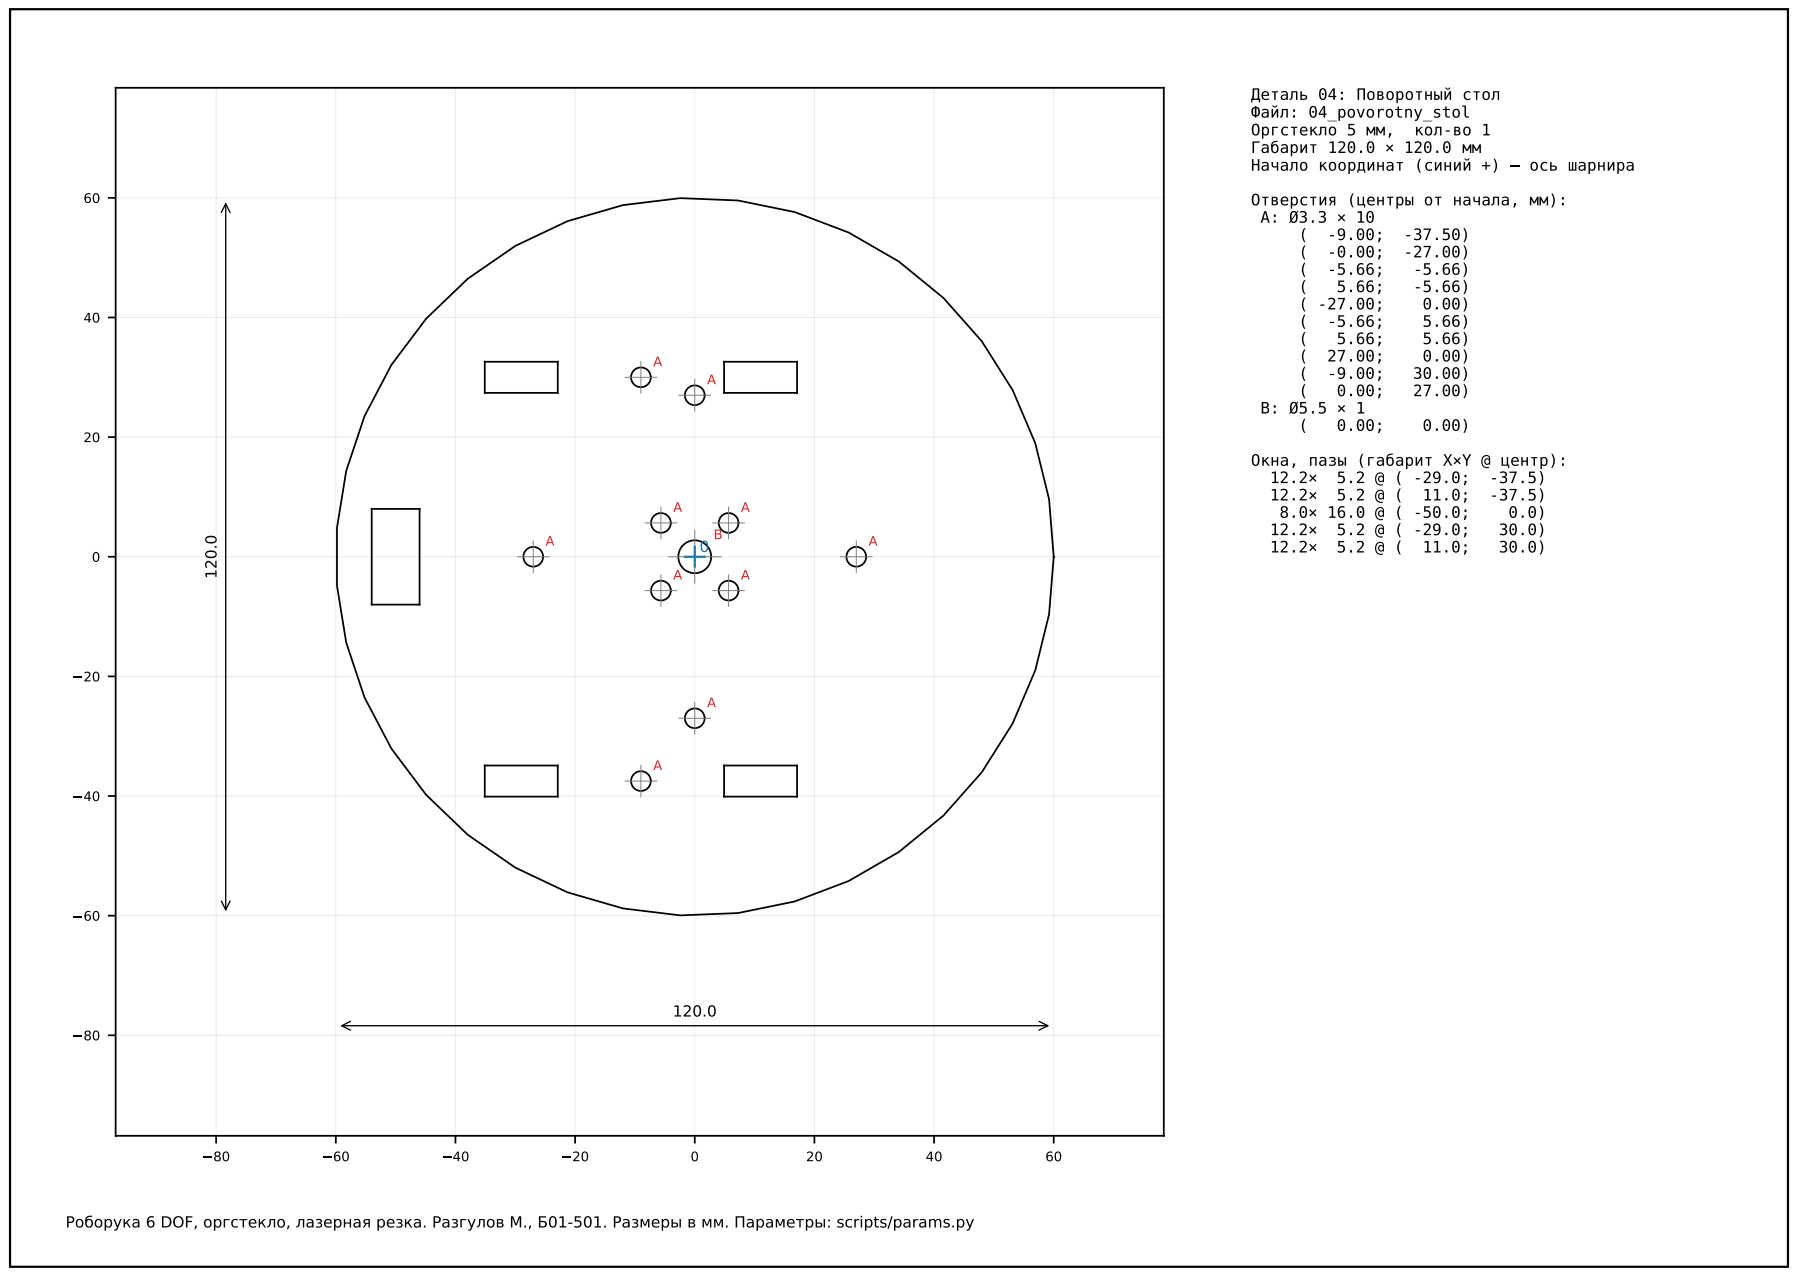
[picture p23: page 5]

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

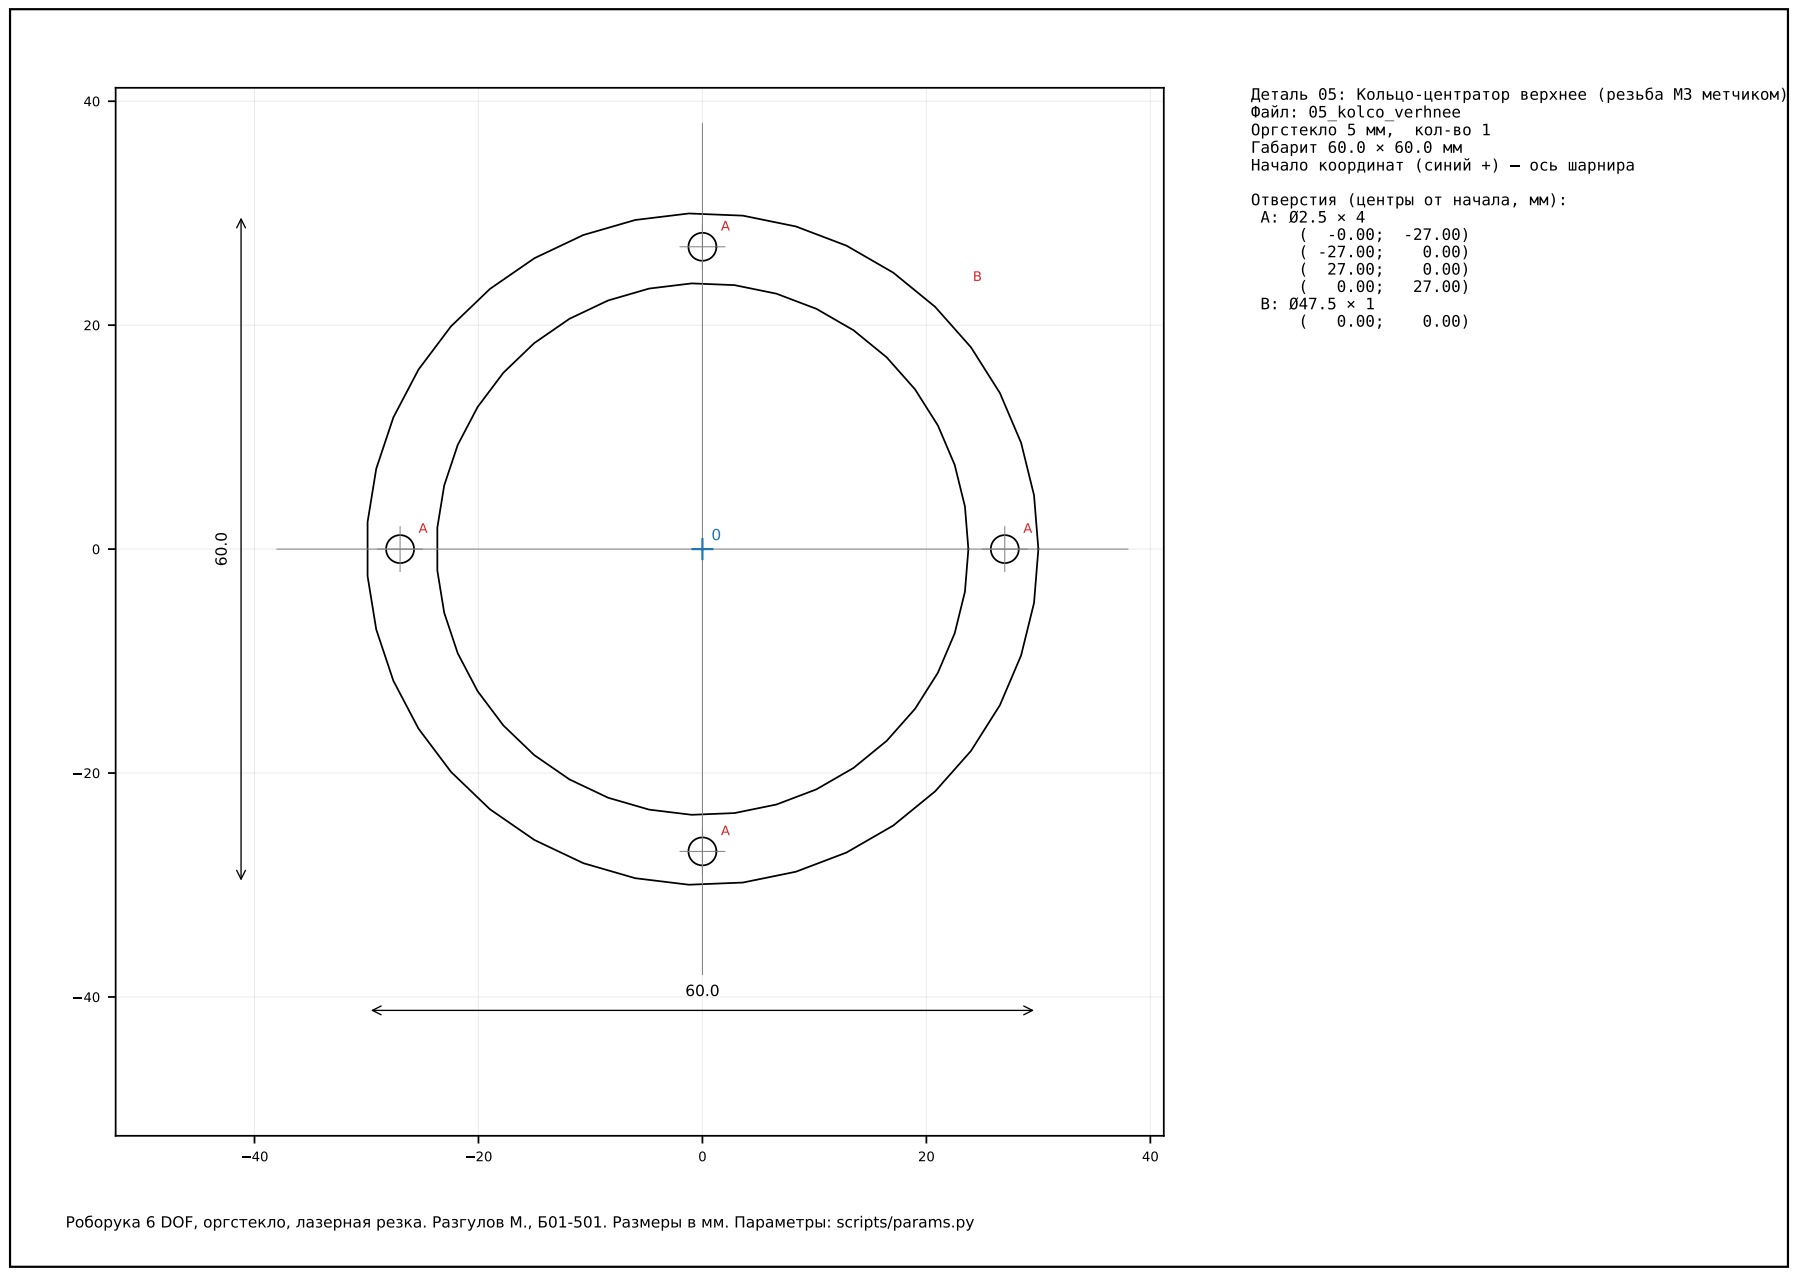
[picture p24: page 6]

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

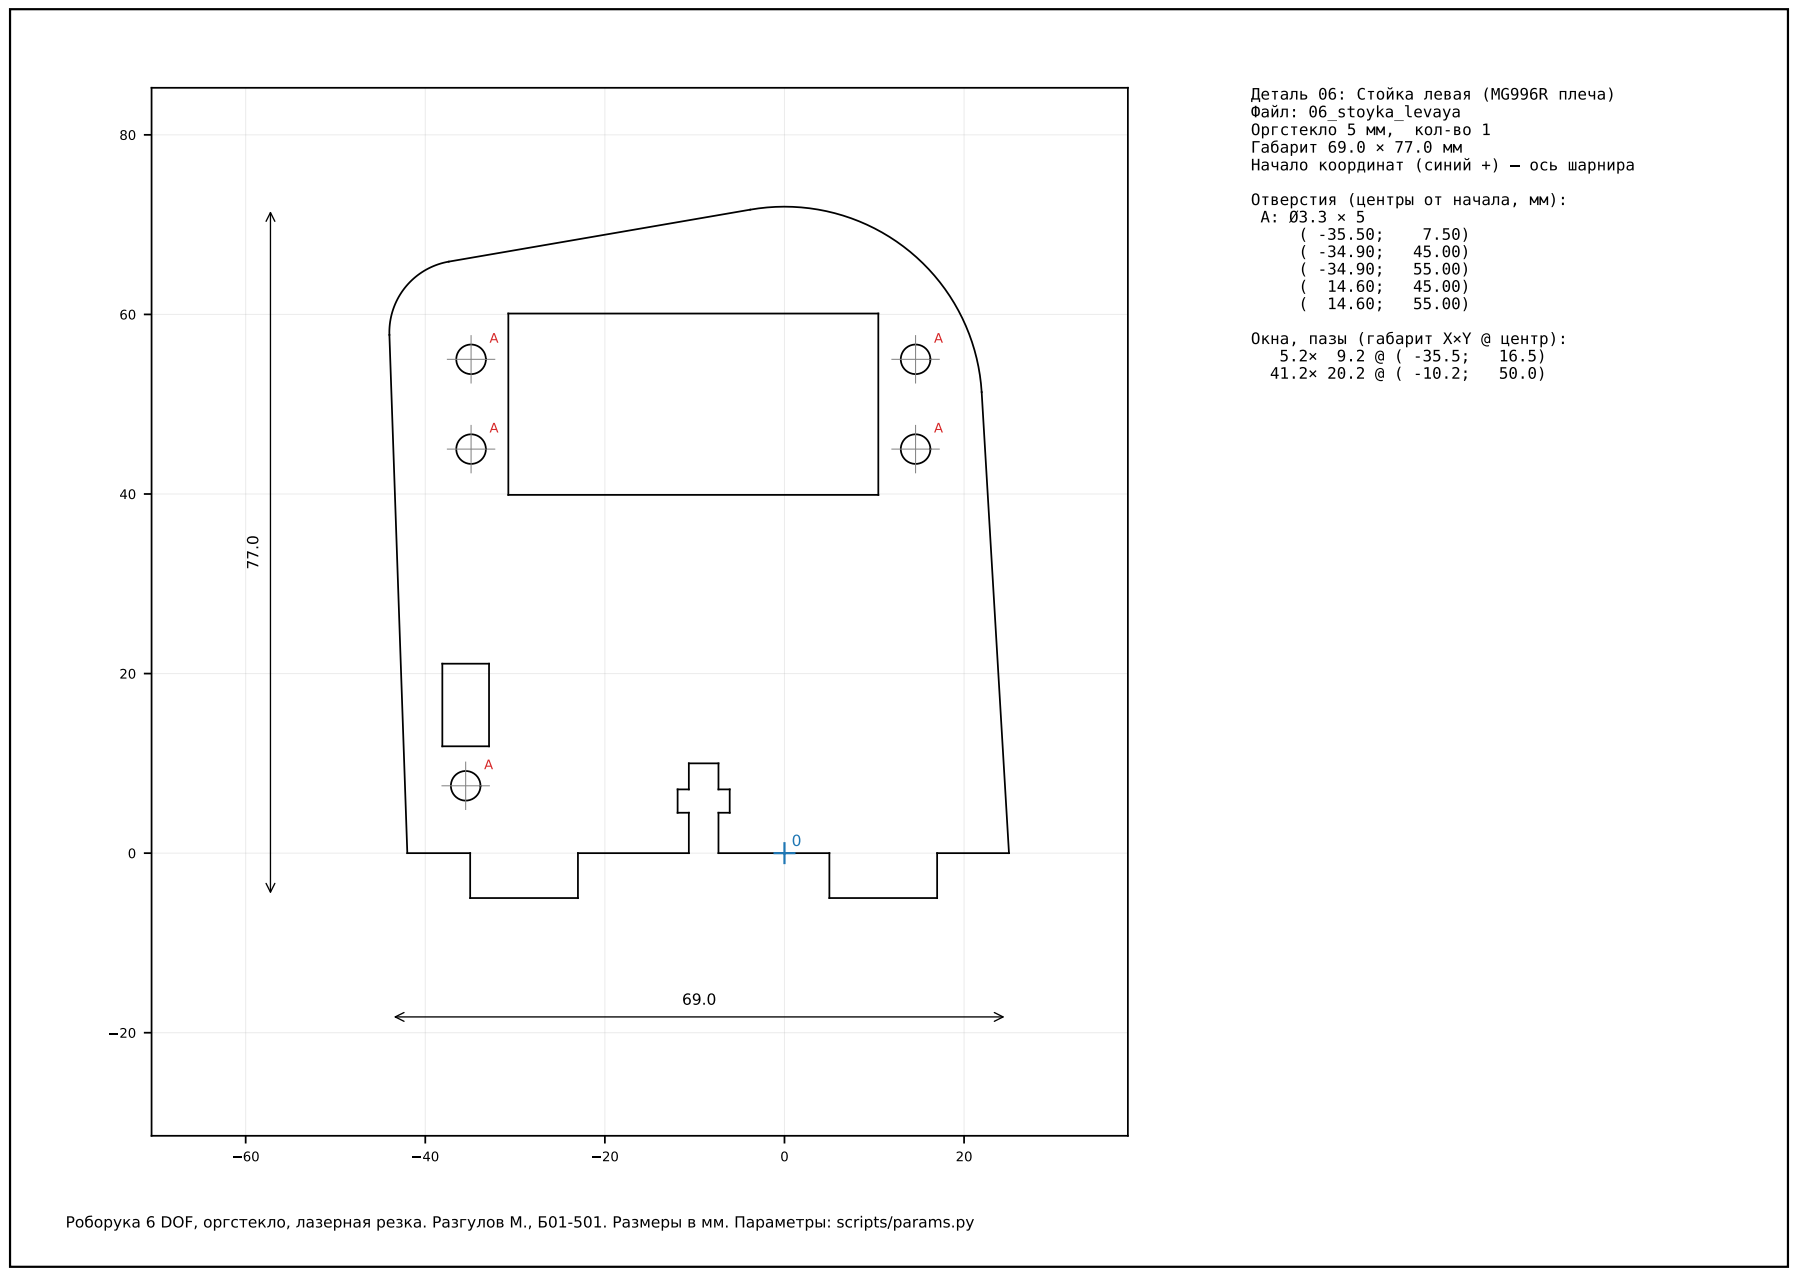
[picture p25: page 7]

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

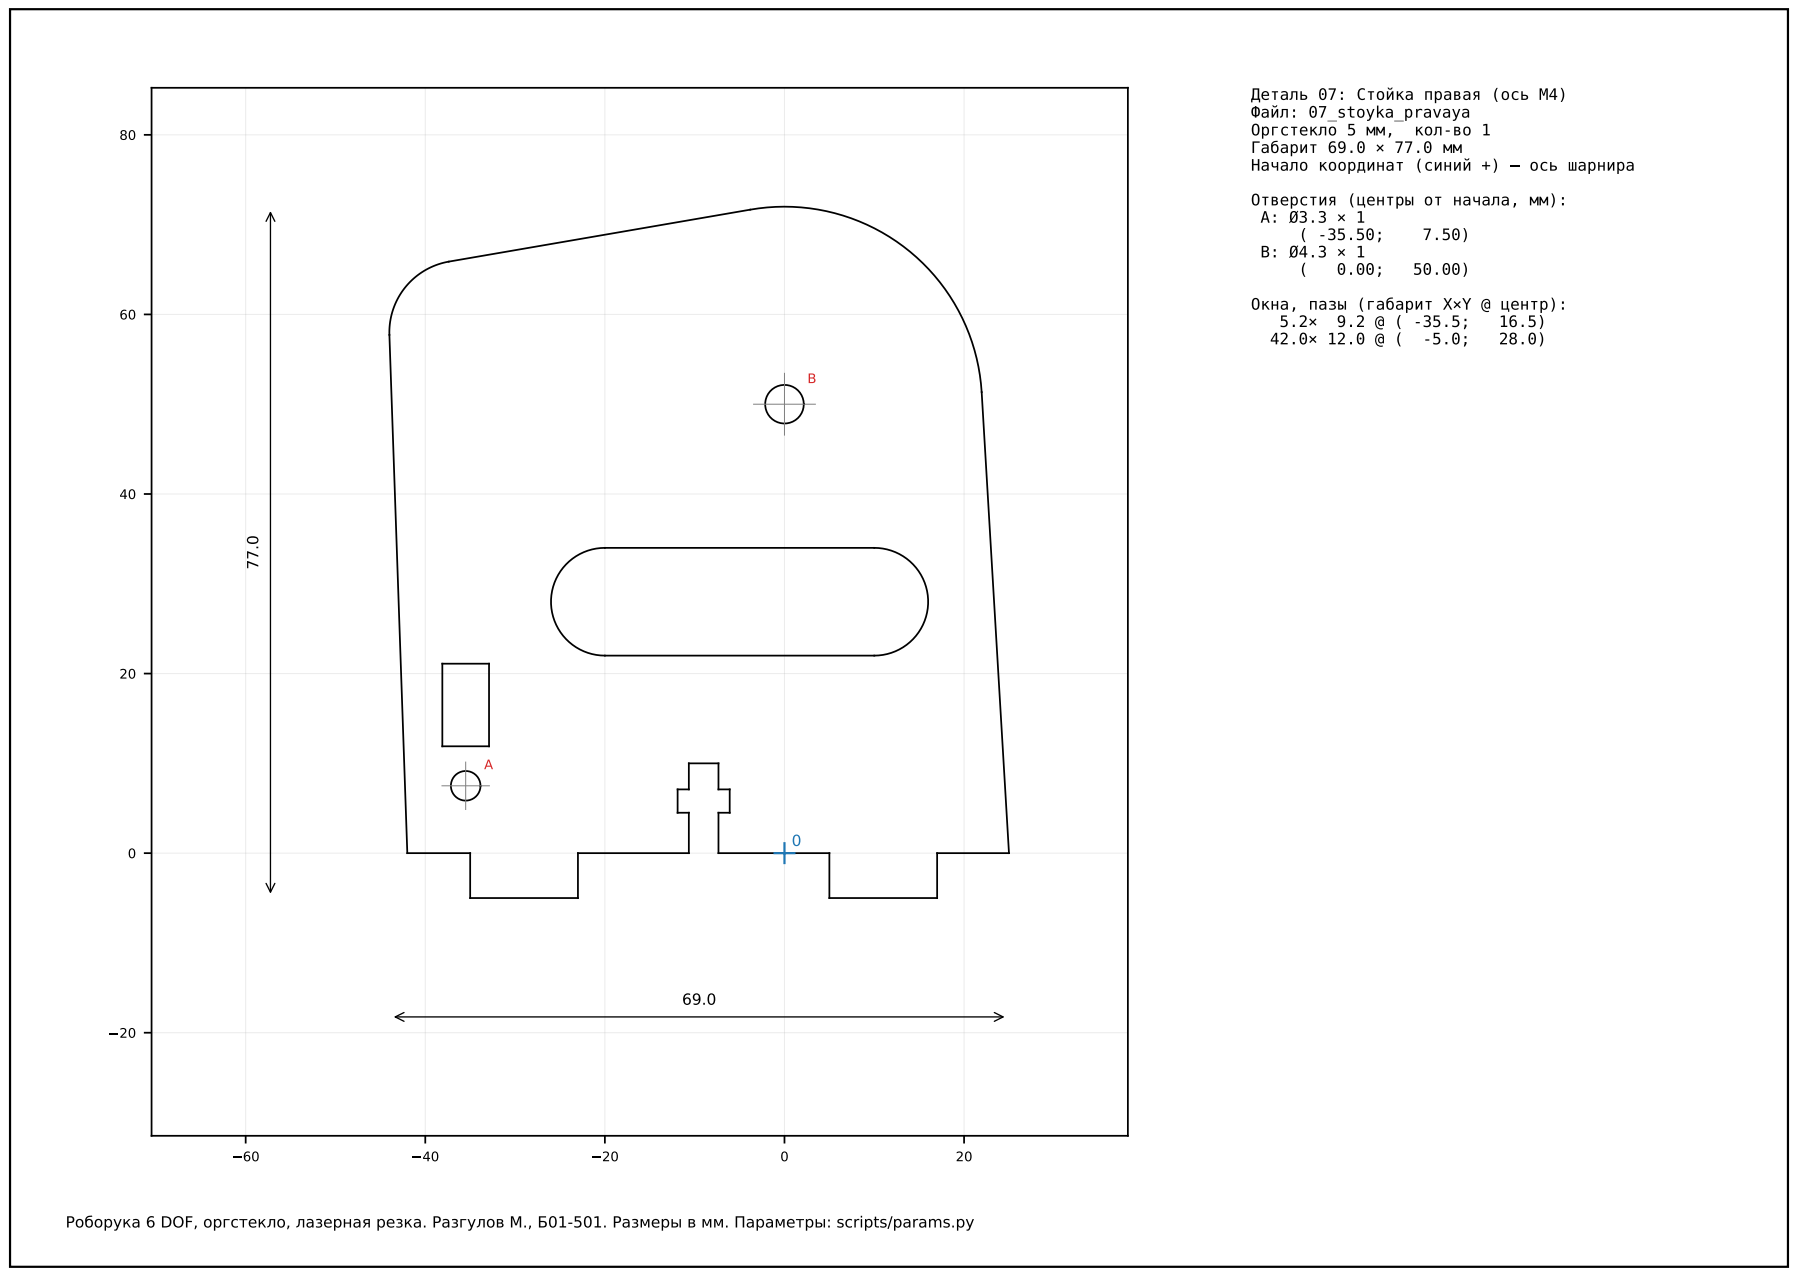
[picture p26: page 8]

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

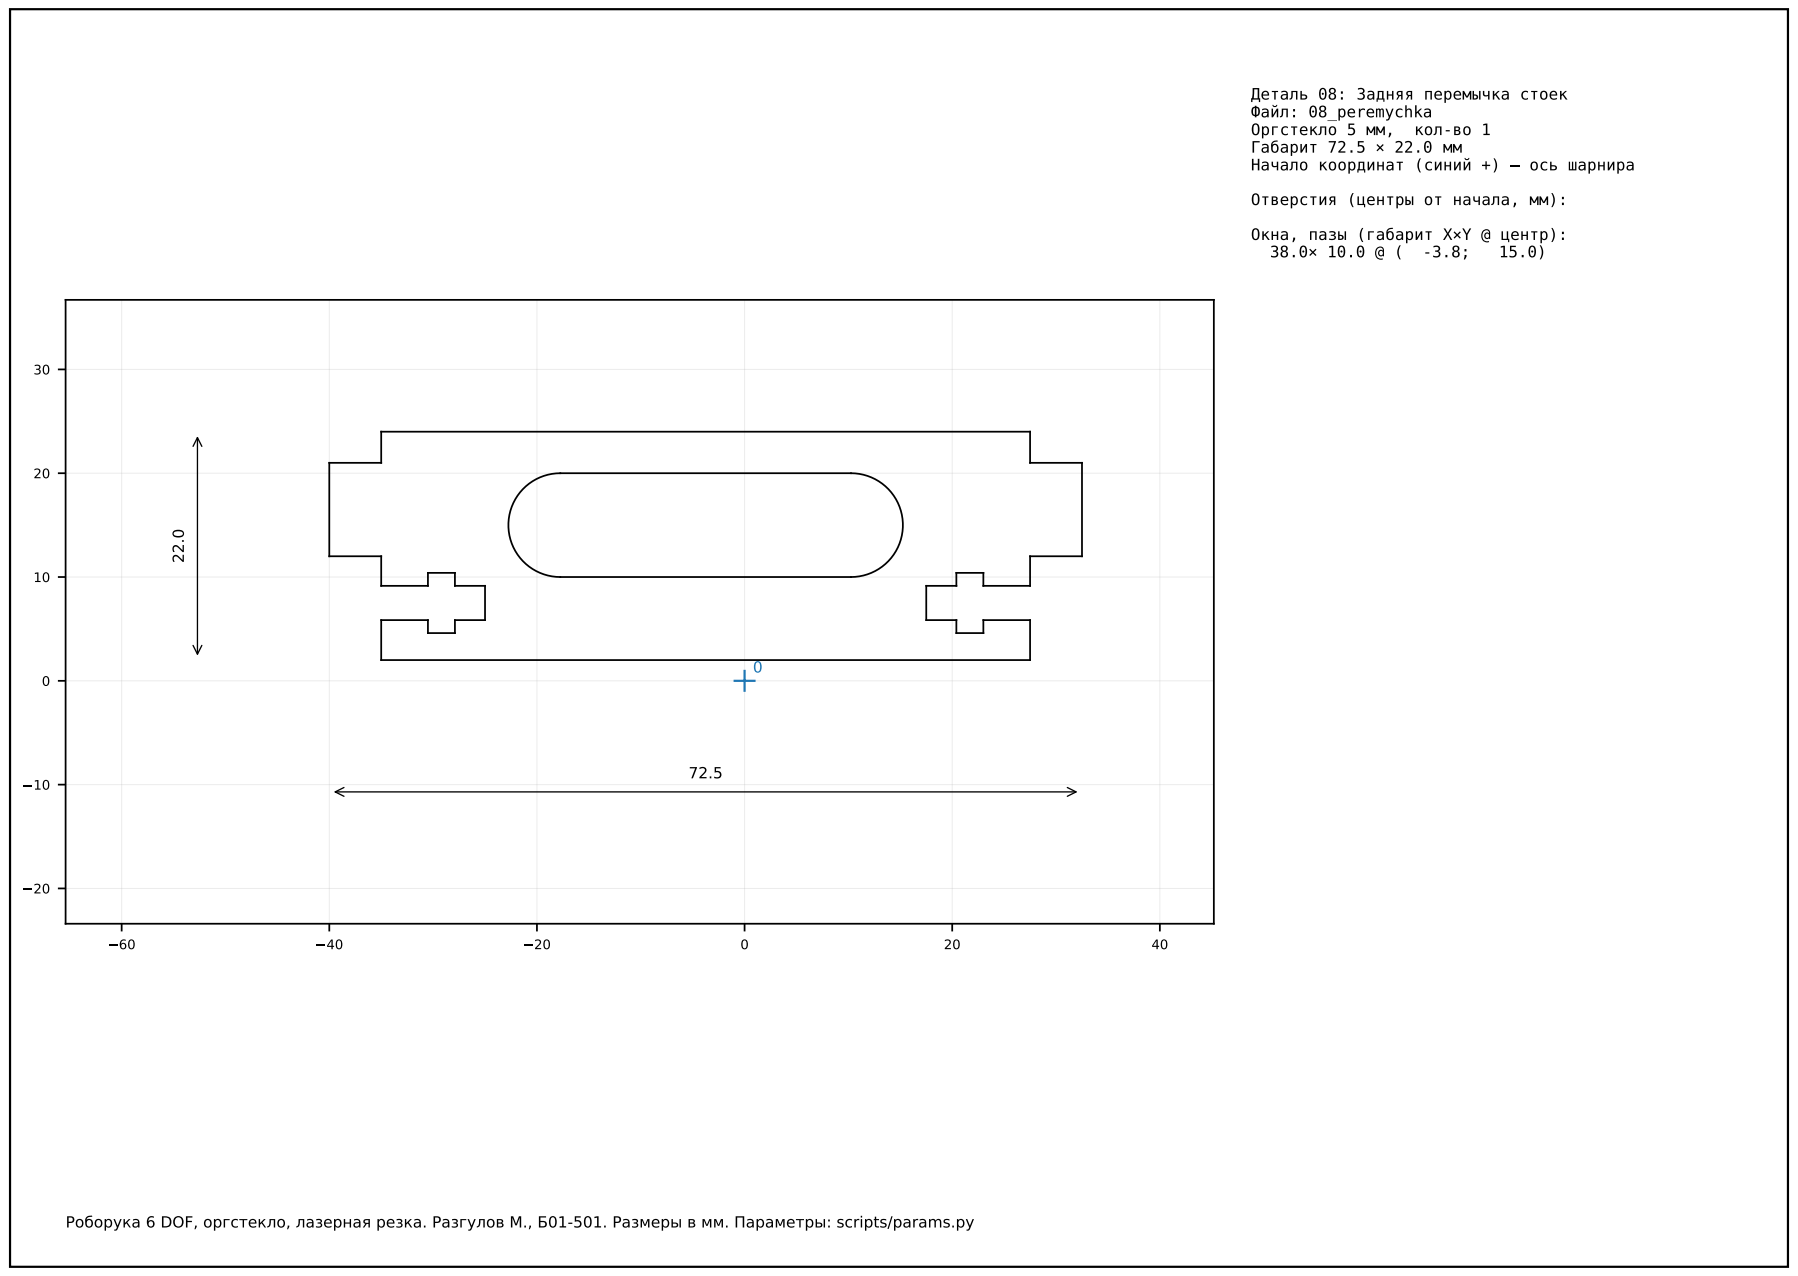
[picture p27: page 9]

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

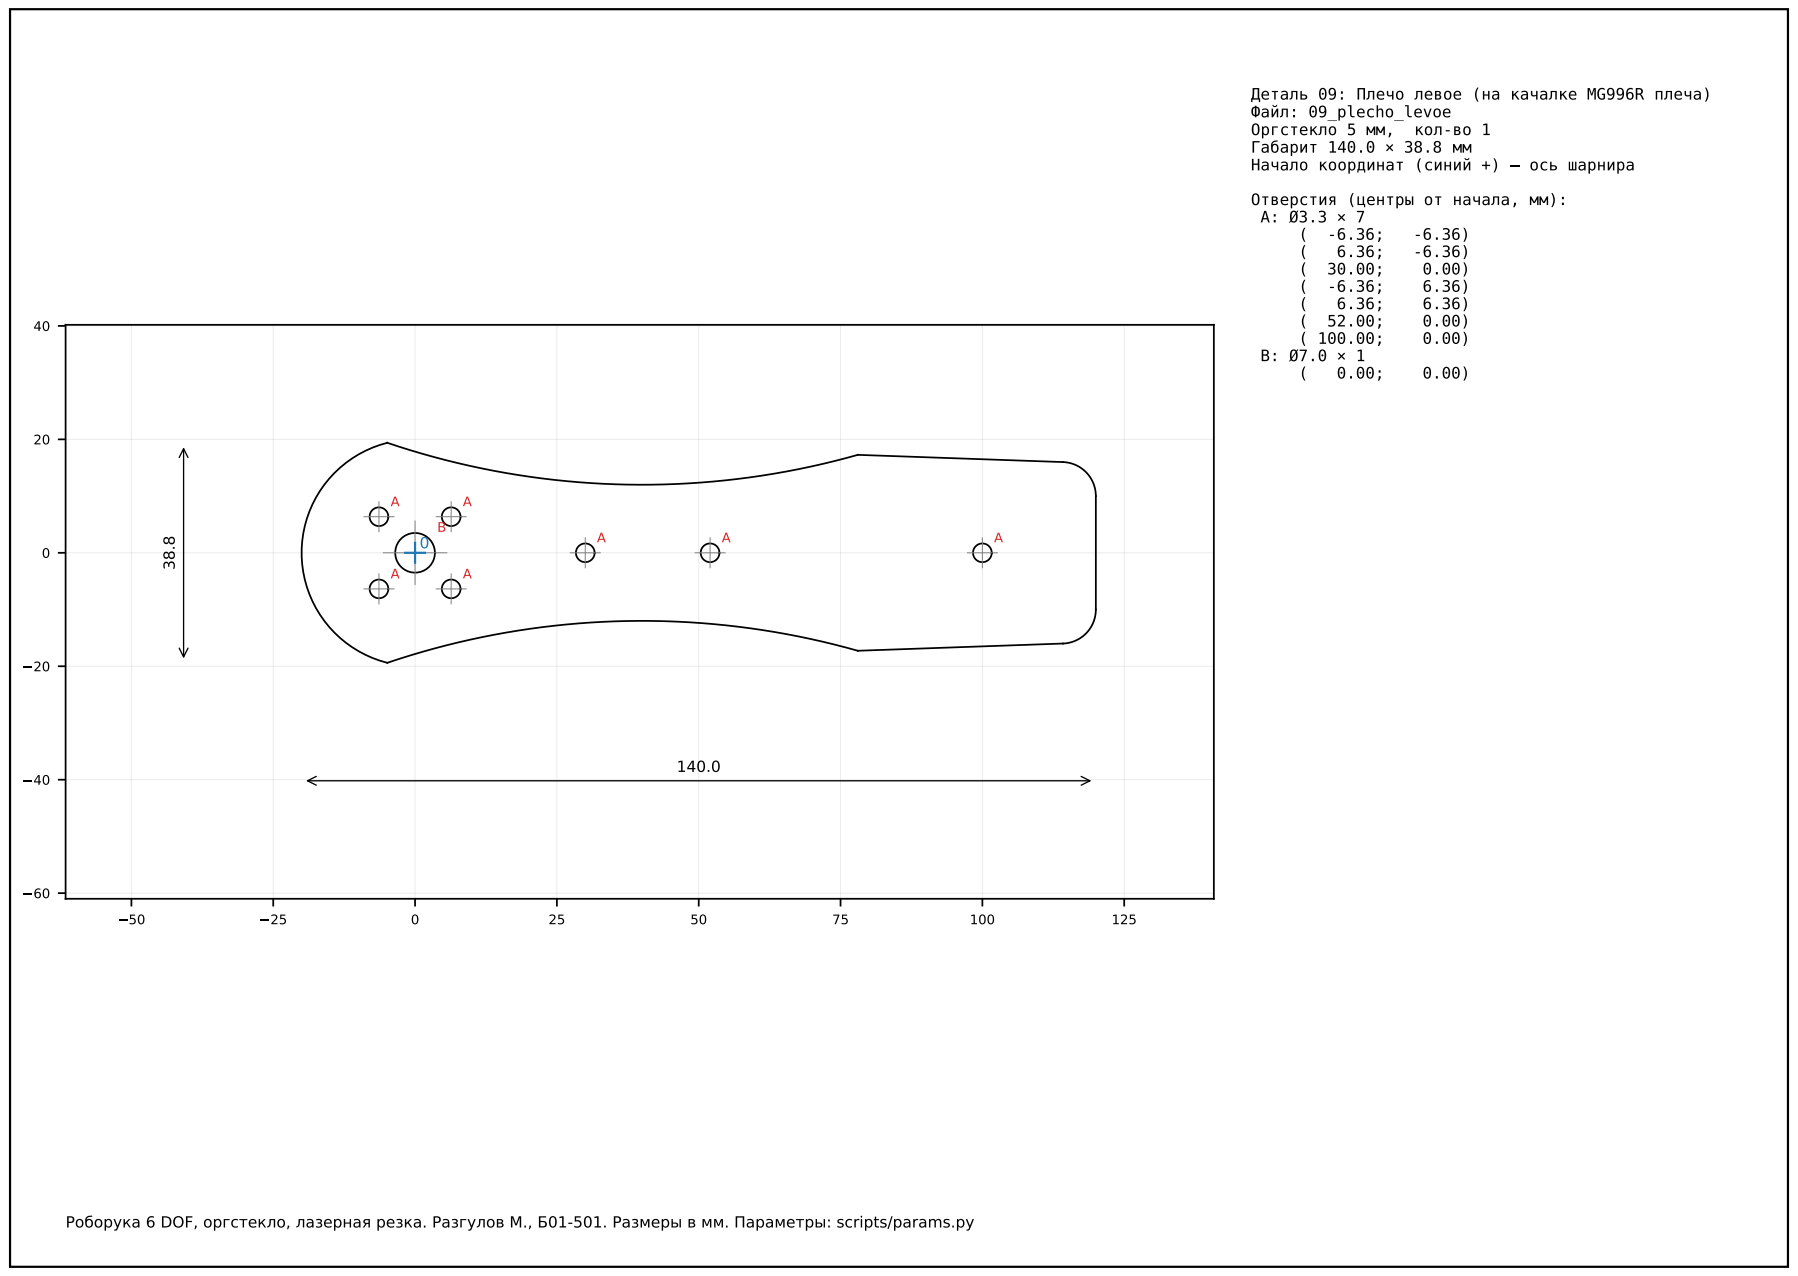
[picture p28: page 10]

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

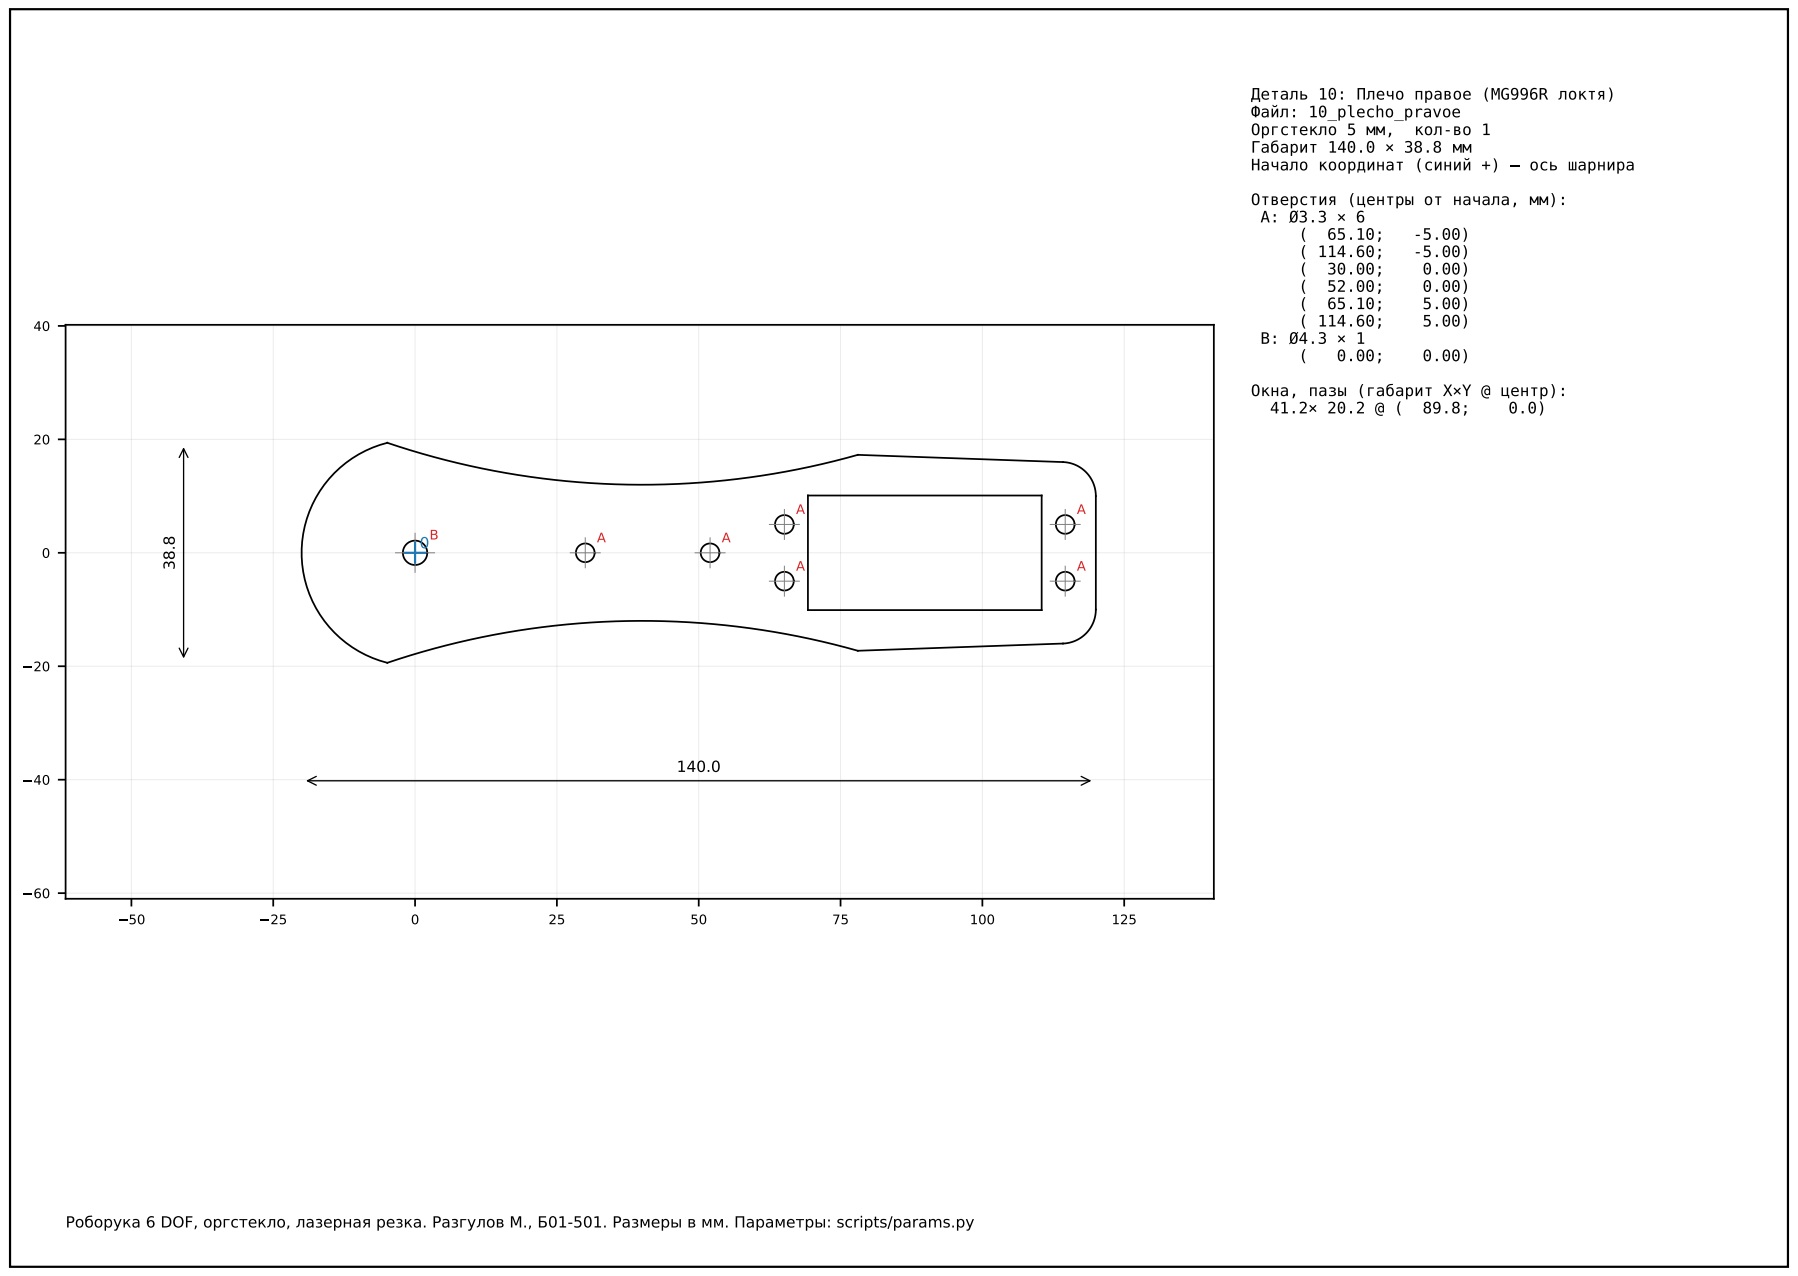
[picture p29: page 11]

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

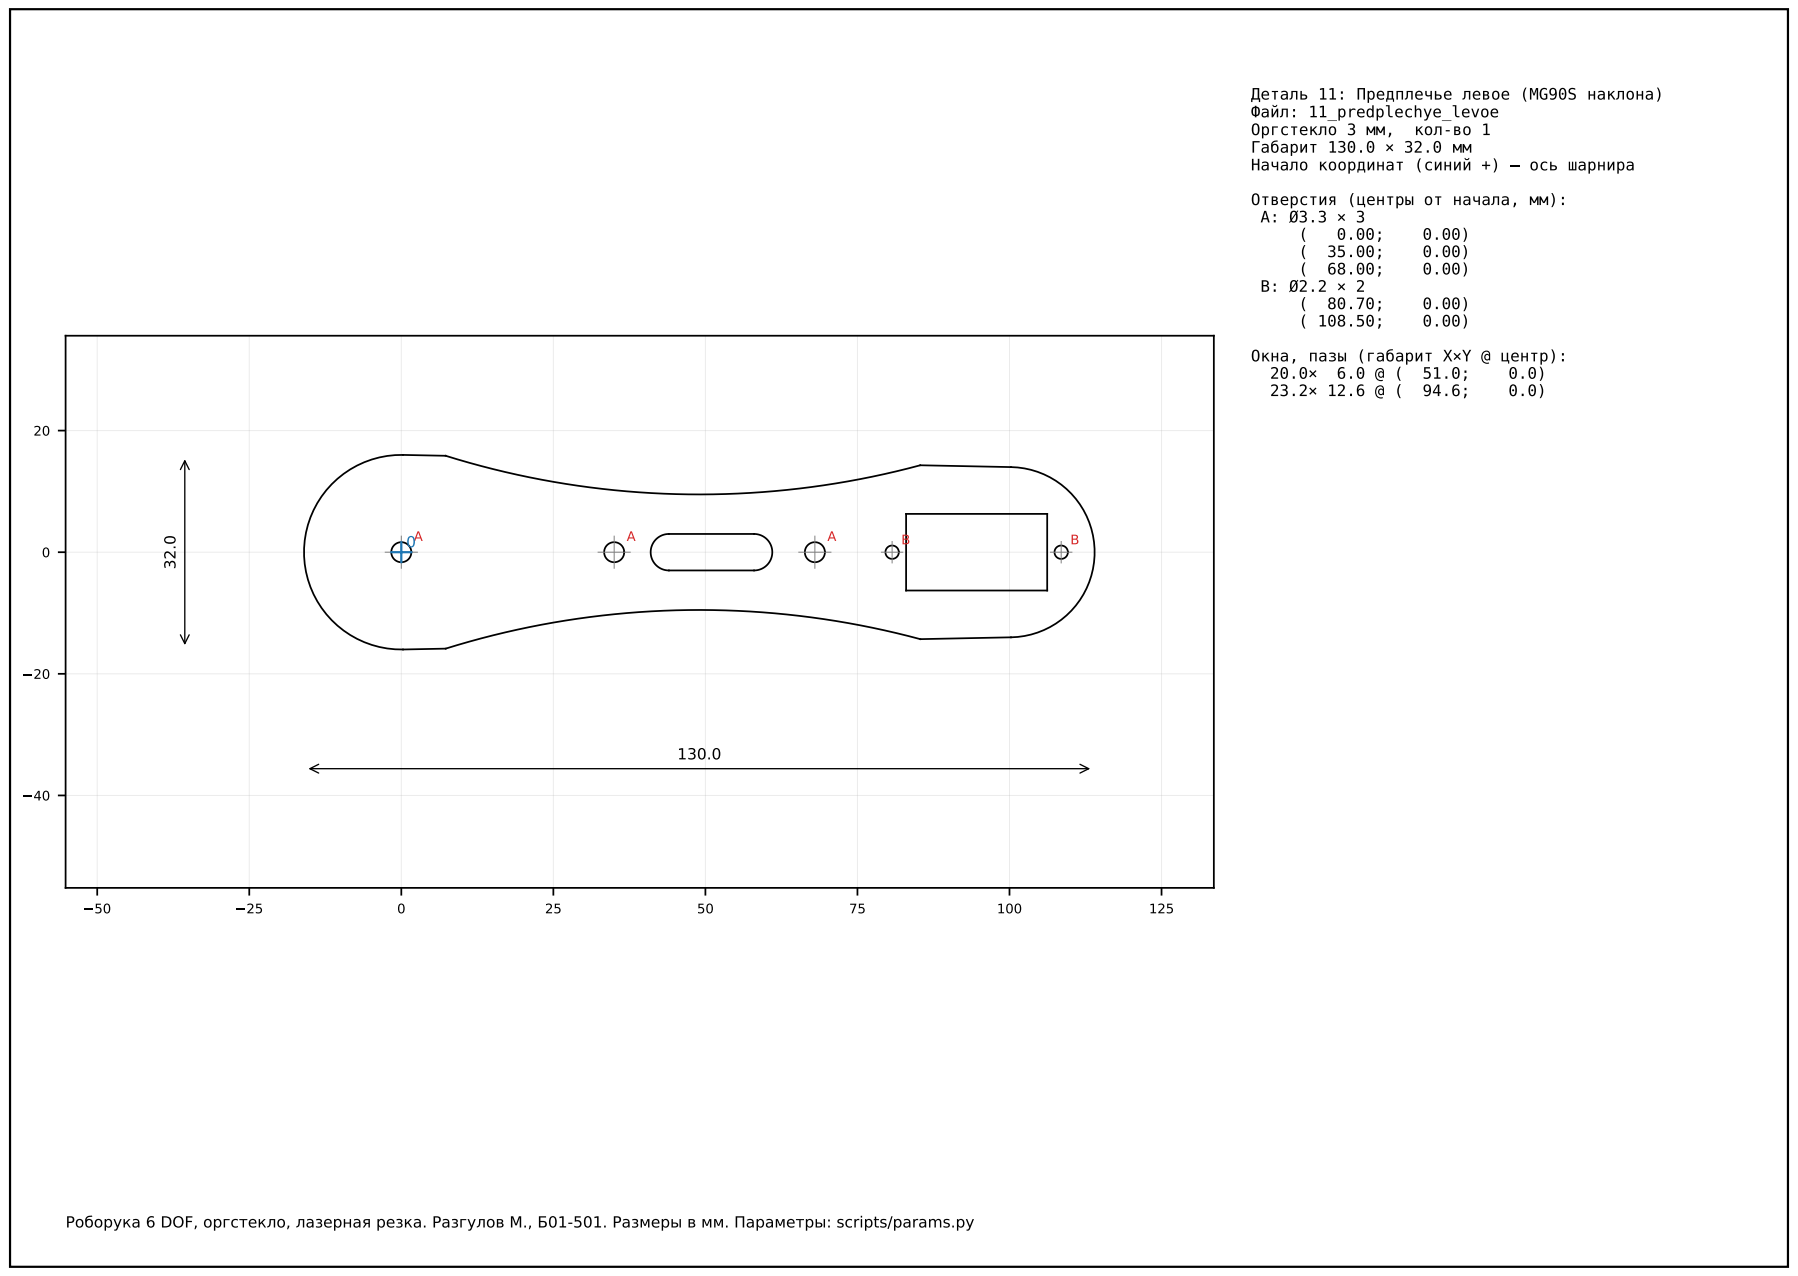
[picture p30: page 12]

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

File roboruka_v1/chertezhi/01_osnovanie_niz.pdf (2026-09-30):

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

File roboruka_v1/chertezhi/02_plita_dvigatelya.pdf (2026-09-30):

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

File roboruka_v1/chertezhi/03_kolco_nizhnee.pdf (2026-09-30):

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

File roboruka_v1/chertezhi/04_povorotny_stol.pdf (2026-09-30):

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

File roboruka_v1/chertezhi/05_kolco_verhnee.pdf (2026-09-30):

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

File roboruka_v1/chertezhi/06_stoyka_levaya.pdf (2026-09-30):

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

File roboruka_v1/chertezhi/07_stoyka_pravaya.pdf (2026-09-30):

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

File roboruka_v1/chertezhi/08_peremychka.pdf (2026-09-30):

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

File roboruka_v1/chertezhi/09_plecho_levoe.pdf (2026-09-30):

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

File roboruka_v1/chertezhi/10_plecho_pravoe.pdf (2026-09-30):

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

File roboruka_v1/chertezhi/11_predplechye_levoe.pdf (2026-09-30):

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

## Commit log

2026-09-30 Механика роборуки v1: детали, чертежи, сборка
    6 DOF, оргстекло 3/5 мм. 21 деталь в STEP и DXF, раскладки листов,
    PDF-чертежи, сборка в позах HOME/WORK, параметрические скрипты CadQuery.
    Claude-Session: https://claude.ai/code/session_01Xv5dmchkUEEphNFgMWBVms
    [00_list_3mm.dxf, 00_list_5mm.dxf, 01_osnovanie_niz.dxf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]
2026-10-01 Среда SolidWorks: нативные SLDPRT с эскизами, макросы, правила
    - solidworks/parts: 21 деталь с деревом Eskiz_kontur -> Plastina,
    Eskiz_otverstiya -> Otverstiya; толщина = T3/T5, отверстия M3 = D_M3
    - solidworks/params.txt: глобальные переменные, детали связаны с файлом
    - макросы BuildParts (data/*.txt -> SLDPRT) и ExportAll (SLDPRT -> STEP)
    - step_detali пересохранены из SolidWorks (геометрия совпадает с генератором)
    - parts.csv: модули M1..M6 и статус gen/manual; manual-детали Python
    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
    [01_osnovanie_niz.SLDPRT, 01_osnovanie_niz.step, 02_plita_dvigatelya.SLDPRT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]
2026-10-01 gitattributes: CRLF для макросов и данных SolidWorks
    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
2026-10-01 Макросы .swp пересохранены SolidWorks
    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
2026-10-01 Модули M1–M6: свои системы координат, порты, подсборки SolidWorks
    - scripts/moduli.py: таблица PORTS — единственное место, где описаны
    стыки модулей (родитель, шарнир, точка, ось); раскладка компонентов
    по модулям в их СК и проверка: рука из модулей по портам в позе WORK
    совпадает с исходной (расхождение ~1e-12 мм)
    - sborka/moduli/M*.step: модули, каждый в своей СК
    - макрос BuildAssembly: покупные изделия STEP -> SLDPRT,
    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
    [51106_separator.SLDPRT, 51106_separator.step, 51106_shayba_niz.SLDPRT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]
2026-10-01 Детали и BuildAssembly.swp пересохранены SolidWorks при закрытии сборки
    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
    [01_osnovanie_niz.SLDPRT, 02_plita_dvigatelya.SLDPRT, 03_kolco_nizhnee.SLDPRT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]
